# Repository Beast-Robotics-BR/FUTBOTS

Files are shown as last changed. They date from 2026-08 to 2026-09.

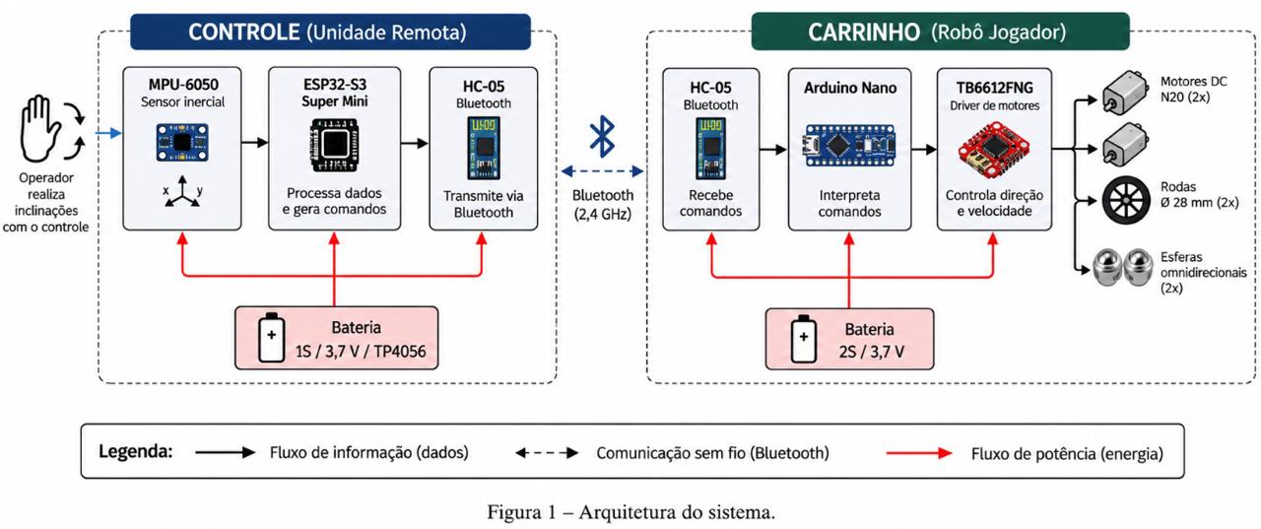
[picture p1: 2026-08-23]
Videos_de_teste/Diagrama_Visual.jpeg

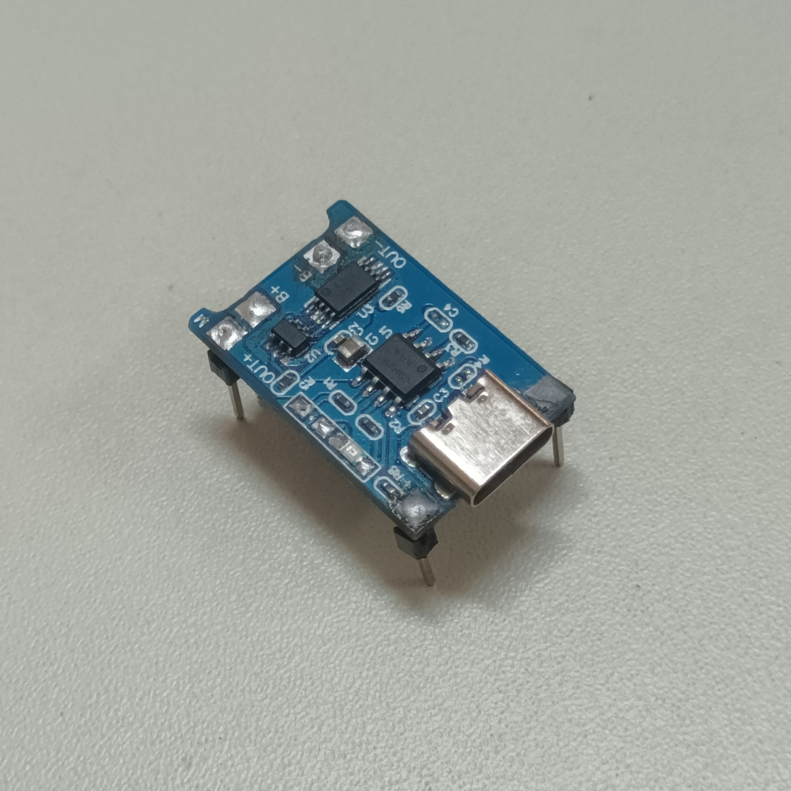
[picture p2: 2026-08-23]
Componentes/TP-4056.jpg

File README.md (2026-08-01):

# CARRINHO ROBÓTICO COM CONTROLE POR GESTOS PARA ROBÔS JOGADORES EM ARENAS DE COMPETIÇÃO: UMA APLICAÇÃO EM FUTEBOL DE ROBÔS

Este repositório reúne os materiais de **hardware** e **software** desenvolvidos para um carrinho controlado remotamente por gestos, com comunicação via **Bluetooth Low Energy (BLE)**, projetado para atuar como robô jogador em **arenas de futebol de robôs**.

---

## ⚠️ Novas Funcionalidades Em Desenvolvimento

### 🎮 Novo Controle Remoto (estilo Gamepad)
- Prezamos pela experiência de uso e, por isso, iniciamos o desenvolvimento de um controle remoto no estilo *gamepad*
- O formato mais clássico facilita a operação em diferentes situações e para diferentes públicos
- Display **OLED** integrado ao controle, capaz de fornecer informações úteis durante a operação
- Longa duração de bateria continua sendo prioridade no novo modelo

---

## Visão Geral

O projeto consiste em um **kit robótico de baixo custo e fácil operação**. Pensamos também na facilidade de reparo e, por isso, optamos por uma abordagem que se beneficia do uso de **software livre (código aberto)** e **manufatura aditiva**. Nosso kit é reparável com poucas ferramentas, além de ter sido projetado para ser resistente e de qualidade.

### Funcionalidades Principais:
- Controle remoto **gestual**, por meio de um sensor inercial (IMU), embarcado no próprio controle
- Controle alternativo via **celular**, tanto para operação normal quanto para testes e ajustes
- Comunicação sem fio via **BLE**, com vinculação por endereço MAC para conexões estáveis
- Múltiplos **níveis de intensidade de PWM**, selecionáveis durante a operação
- **Gatilhos físicos** e **botão multifunção** para ações rápidas de controle
- **Programação por blocos**, através de um web app, permitindo customizar o comportamento do carrinho
- Painel de depuração via **Web Bluetooth**, acessível pelo navegador

---

## 🛠 Hardware

### Componentes Principais
- **ESP32-S3 Super Mini** — controladora central, embarcada no controle remoto
- **Arduino Nano** — controlador embarcado no carrinho
- **Módulo IMU (MPU-6050)** — leitura de inclinação (pitch/roll) para o controle gestual
- **Display OLED SSD1306** (interface SPI, 7 pinos) — feedback visual no controle
- **Gatilhos físicos** e **botão multifunção**
- Comunicação via **Bluetooth Low Energy (BLE)**, compatível com **Web Bluetooth**

---

## 🔧 Arquitetura de Comunicação

- Comunicação **BLE** entre o controle (ESP32-S3) e o carrinho (Arduino Nano)
- Uso do **Nordic UART Service** para garantir compatibilidade com **Web Bluetooth**
- **Vinculação por MAC address**, salva em memória não volátil (NVS), evitando reconexões indesejadas com outros dispositivos
- **Modo CONFIG**: o ESP32 passa a anunciar com UUIDs proprietários de 128 bits, permitindo o envio e o salvamento de perfis de PWM na memória do dispositivo
- **Painel de depuração Web Bluetooth (HTML)**, com múltiplos modos de conexão, D-pad virtual, monitor serial e contadores de pacotes TX/RX

---

## 🎮 Sistema de Controle Gestual

- Leitura de **pitch/roll** via MPU-6050, traduzida em comandos de direção do carrinho
- **Três níveis de intensidade de PWM**, ajustáveis conforme a situação de jogo
- **Gatilhos físicos** (GPIO) para funções adicionais de controle
- **Botão multifunção**:
  - 1 clique → recalibração do sensor
  - 2 cliques → bloqueia/desbloqueia o controle
  - Pressão longa (5s) → entra no **modo CONFIG**

---

## ⚙️ Notas Técnicas

- Durante o desenvolvimento, identificamos que módulos baratos vendidos como "HC-05" eram, na verdade, clones com chip Jieli, operando com serviço/característica BLE próprios — o que exigiu ajustes no mapeamento de UUIDs
- A arquitetura de comunicação BLE passou por múltiplas revisões (filtros de escaneamento, arquitetura de callbacks) até garantir estabilidade de conexão

---

## 🎯 Aplicações

- Robô jogador em **arenas de futebol de robôs** e competições similares
- Ensino de **robótica e automação** com foco em controle gestual
- Base para **prototipagem** de sistemas de controle remoto sem fio de baixo custo

---

## Muito obrigado pela atenção !!!

---

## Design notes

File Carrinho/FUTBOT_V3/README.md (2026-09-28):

# RoverLab V3 Modular

Firmware para Arduino Nano + TB6612FNG + HM-10 com controle manual, perfil PWM, EEPROM e programação por blocos.

## Arquivos

- `FUTBOT_V3.ino`: aplicação principal, protocolo, motores, EEPROM e executor de blocos.
- `Config.h`: pinagem, parâmetros e seleção de polaridade.
- `Leds.h`: estados e padrões dos LEDs.

Abra o arquivo `FUTBOT_V3.ino` pelo Arduino IDE mantendo os três arquivos na mesma pasta.

## Escolha do tipo de LED

Edite somente esta linha em `Config.h`:

```cpp
const bool LED_ACTIVE_HIGH = true;
```

Use:

```cpp
true  // catodo comum: HIGH acende
false // anodo comum: LOW acende
```

Se o seu módulo LED tiver transistores ou uma placa intermediária que inverta o sinal, use o valor que corresponde ao nível lógico que efetivamente acende o LED.

## Estados dos LEDs

- Azul fixo: BLE conectado.
- Azul piscando: BLE desconectado.
- Vermelho pulsando: janela de configuração desbloqueada.
- Vermelho fixo: reservado para falha crítica.
- Verdes fixos em quantidade 1, 2 ou 3: nível de movimento selecionado.
- Verde alternado: upload de programa em andamento.
- Verde correndo: programa por blocos em execução.

Os pinos permanecem:

| LED | Pino |
|---|---:|
| Verde 1 | D6 |
| Verde 2 | D9 |
| Verde 3 | D10 |
| Vermelho | D4 |
| Azul | D2 |

## Configuração indispensável

O perfil de velocidade continua disponível no protocolo V3:

```text
@C,UNLOCK*CRC8;
@C,PROFILE,45,85,135*CRC8;
@C,GET*CRC8;
```

A alteração só é aceita dentro da janela de 5 segundos após `UNLOCK`. O perfil é validado e gravado em dois slots alternados da EEPROM.

A programação por blocos continua usando:

```text
@P,BEGIN,TAMANHO,CRC16*CRC8;
@P,DATA,OFFSET,HEX*CRC8;
@P,COMMIT*CRC8;
@P,START*CRC8;
@P,STOP*CRC8;
```

## Teste inicial

1. Selecione `LED_ACTIVE_HIGH` conforme o carrinho.
2. Grave o firmware com as rodas suspensas.
3. Abra o terminal em 38400 baud.
4. Confira o azul: ele deve piscar desconectado e ficar fixo conectado.
5. Envie `@C,UNLOCK*3B;`. O vermelho deve pulsar por 5 segundos.
6. Envie o perfil de teste e observe os LEDs verdes.
7. Teste o programa por blocos e mantenha `@P,STOP*0A;` acessível.

## Watchdog e execução de blocos

O watchdog de 300 ms protege somente o modo manual. Durante `P,START`, o executor mantém o programa ativo até a duração de cada passo terminar; assim, `01 01 32` permanece avançando por 5 segundos. A troca entre passos ocorre na expiração do passo, sem pausa artificial. `P,STOP` e o frame enquadrado `STOP` continuam interrompendo imediatamente o programa e os motores.

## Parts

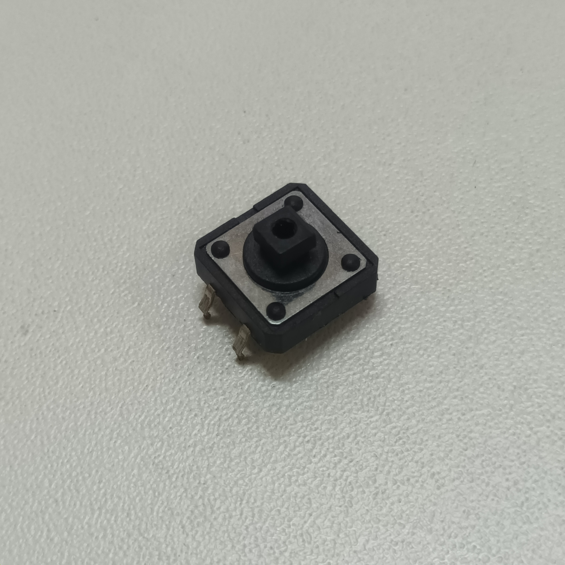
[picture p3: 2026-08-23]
Componentes/BOTÃO 12MM.jpg

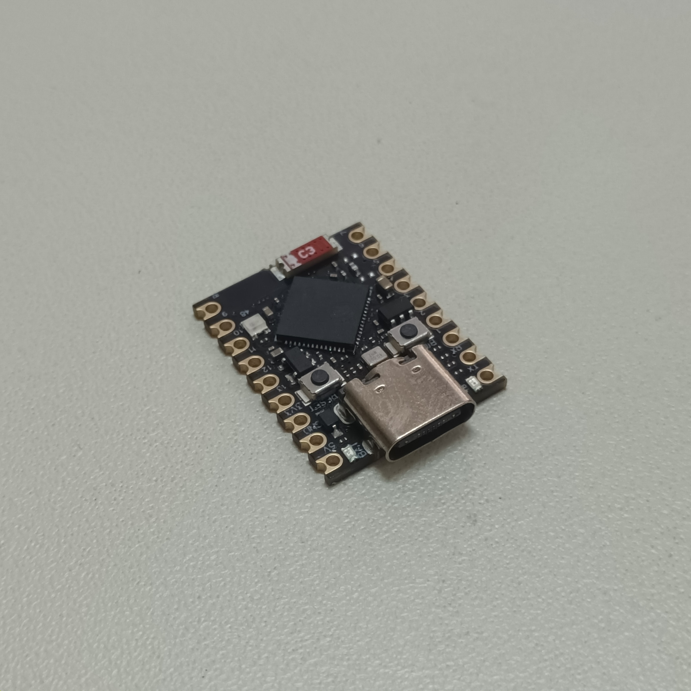
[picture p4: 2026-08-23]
Componentes/ESP32-S3.jpg

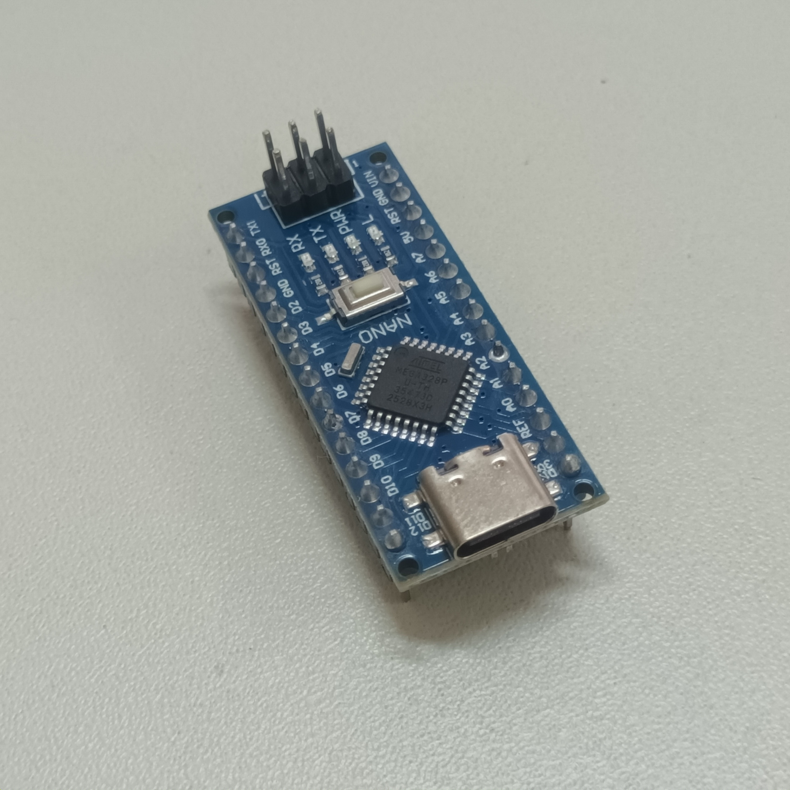
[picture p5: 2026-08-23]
Componentes/ARDUINO-NANO.jpg

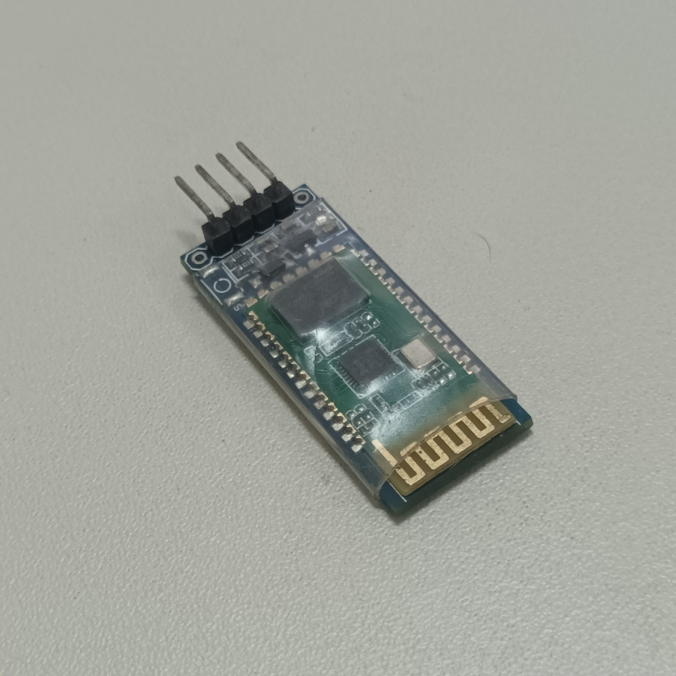
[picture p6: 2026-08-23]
Componentes/HC-05.jpg

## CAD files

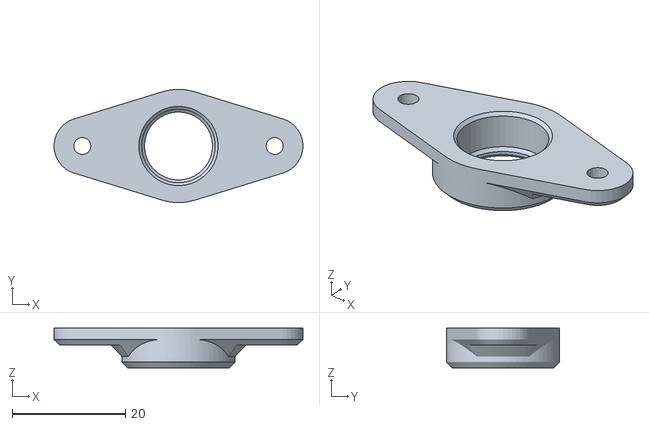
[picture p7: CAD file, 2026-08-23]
Carrinho/Modelos-3D/TRAVA_ESFERA.stl
44.0 x 20.0 x 7.00

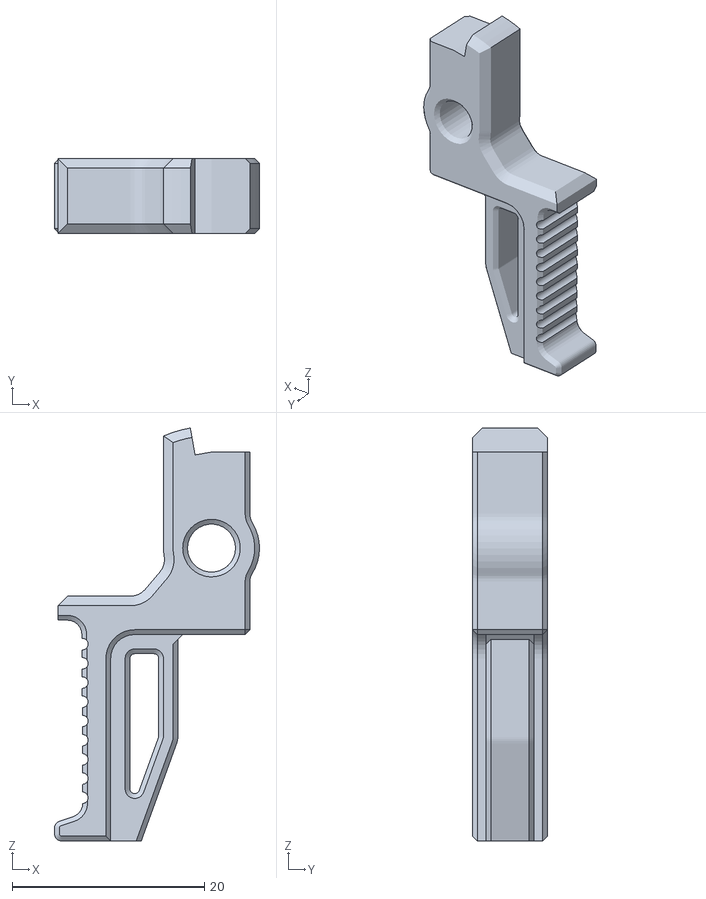
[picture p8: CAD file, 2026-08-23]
Controle_Gestual/Modelos-3D/Gatilho.stl
21.4 x 7.80 x 43.0

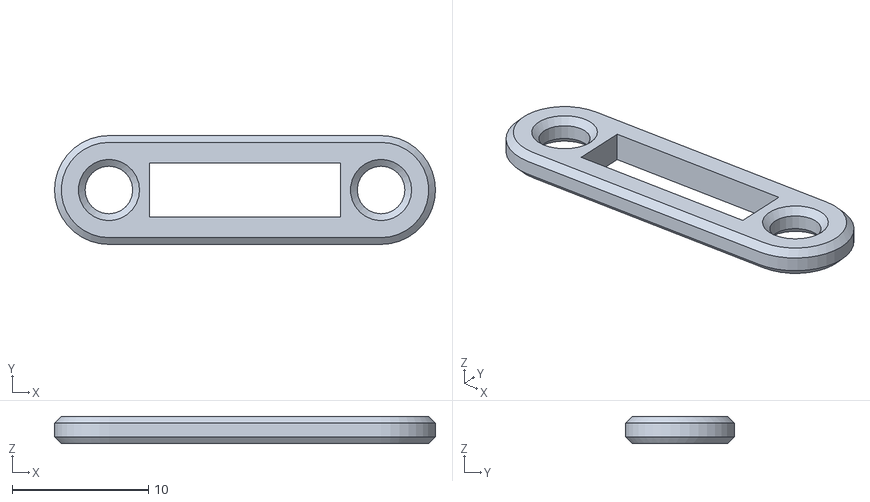
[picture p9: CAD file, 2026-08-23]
Carrinho/Modelos-3D/TRAVA_INTERRUPTOR.stl
28.0 x 8.00 x 2.00

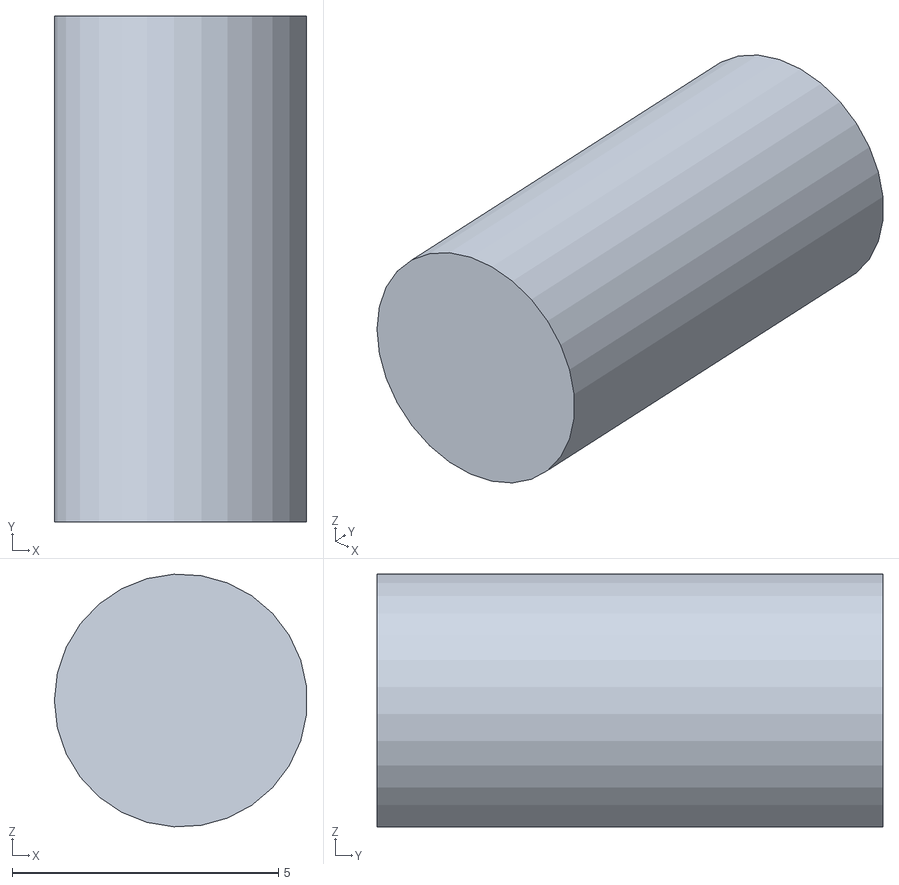
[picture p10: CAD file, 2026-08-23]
Controle_Gestual/Modelos-3D/Eixo_gatilho.stl
4.74 x 9.50 x 4.74

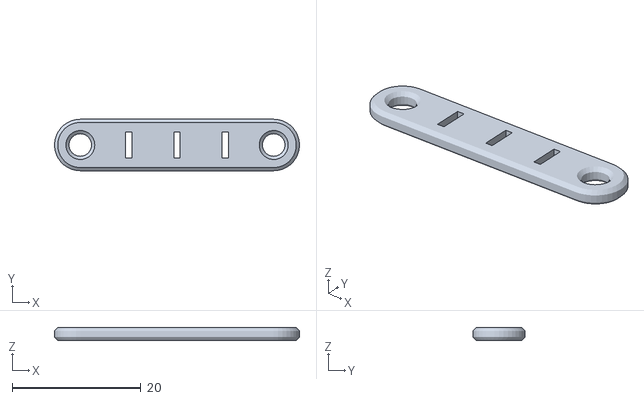
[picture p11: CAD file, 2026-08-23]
Carrinho/Modelos-3D/TRAVA_LEDS.stl
38.0 x 8.00 x 2.00

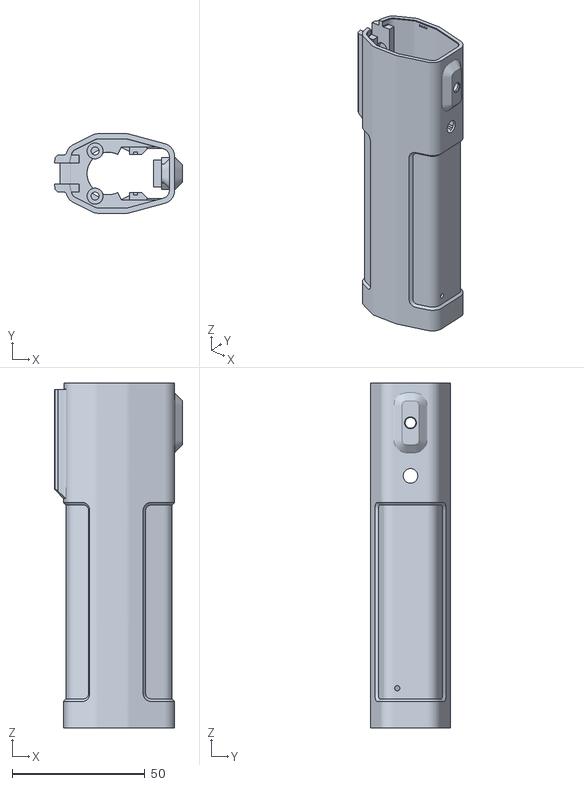
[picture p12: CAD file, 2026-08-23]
Controle_Gestual/Modelos-3D/Corpo_principal.stl
48.3 x 30.0 x 130.0

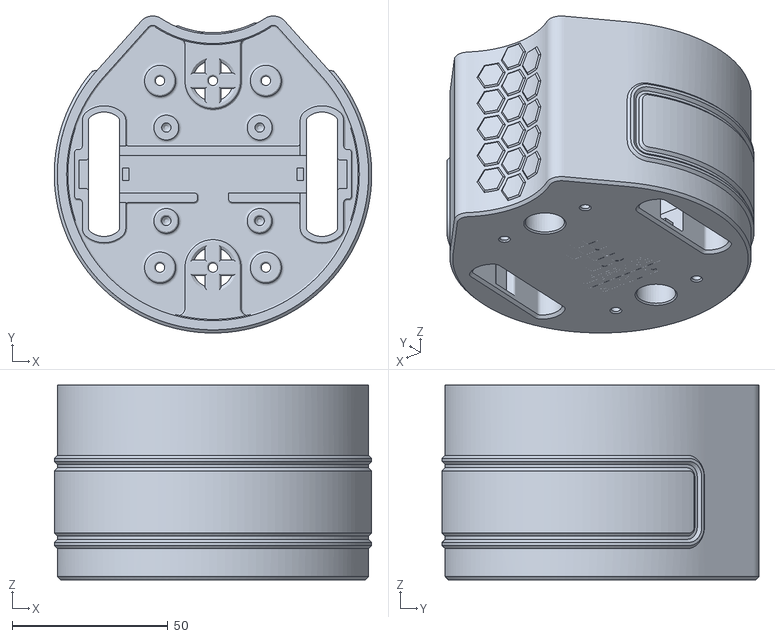
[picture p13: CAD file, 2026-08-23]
Carrinho/Modelos-3D/CASE_EXT.stl
102.0 x 101.8 x 62.5

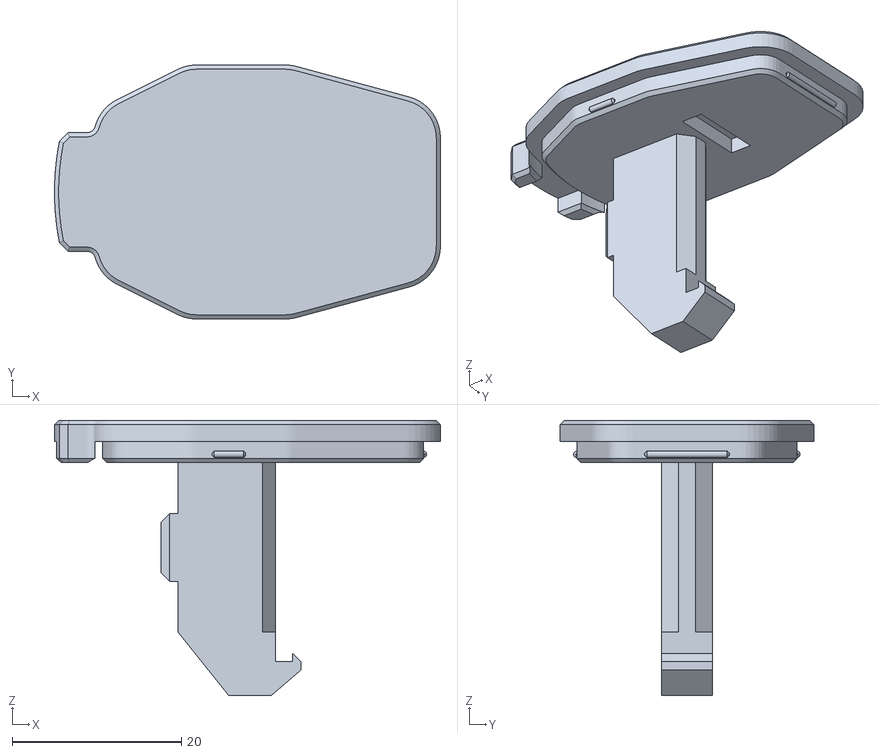
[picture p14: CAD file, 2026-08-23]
Controle_Gestual/Modelos-3D/Tampa_superior.stl
45.6 x 30.0 x 32.5

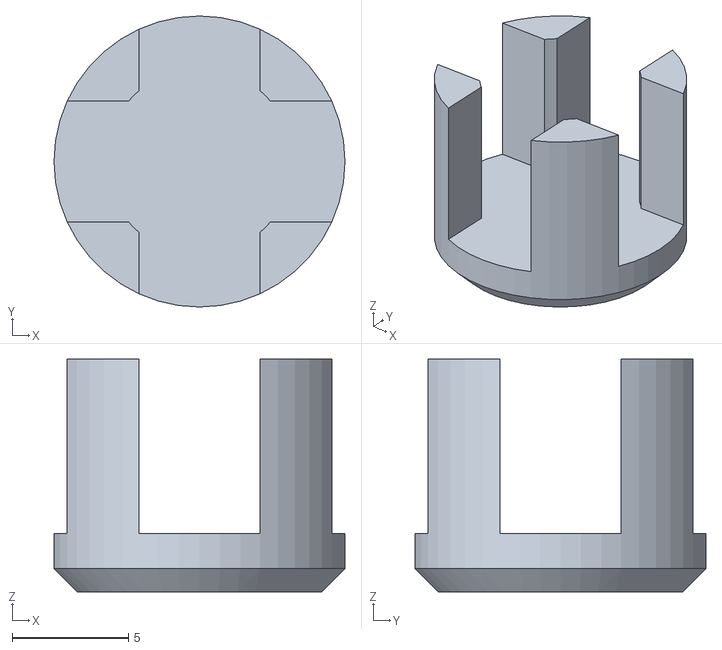
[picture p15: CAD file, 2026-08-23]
Carrinho/Modelos-3D/ESF_AJUSTE.stl
12.5 x 12.5 x 10.0

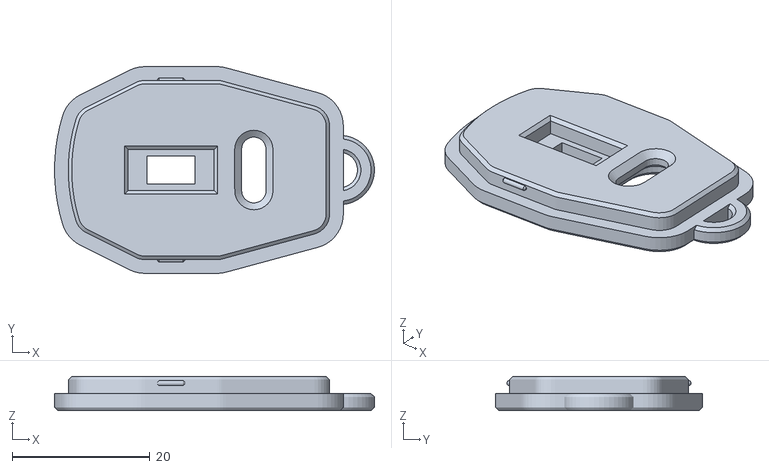
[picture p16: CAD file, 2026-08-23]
Controle_Gestual/Modelos-3D/Tampa_inferior.stl
46.4 x 30.0 x 5.00

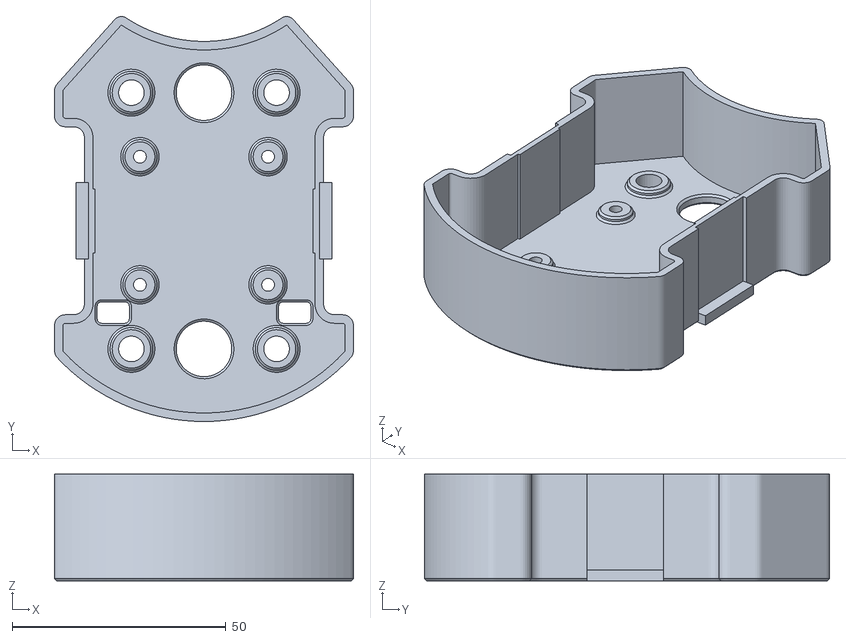
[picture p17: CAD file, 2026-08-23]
Carrinho/Modelos-3D/CASE_INT.stl
70.1 x 94.8 x 25.0

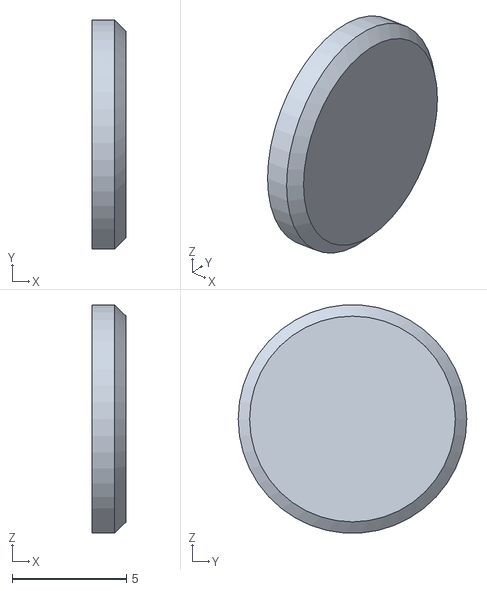
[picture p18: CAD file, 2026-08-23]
Controle_Gestual/Modelos-3D/Botão_externo.stl
1.50 x 10.0 x 9.97

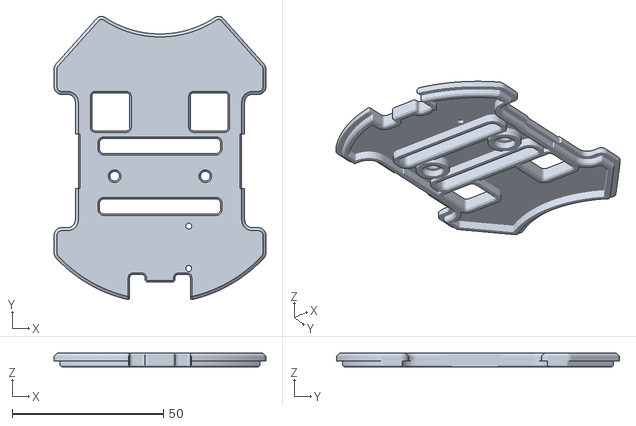
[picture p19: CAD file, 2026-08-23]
Carrinho/Modelos-3D/TAMPA_CASE_INT.stl
70.1 x 93.6 x 4.50

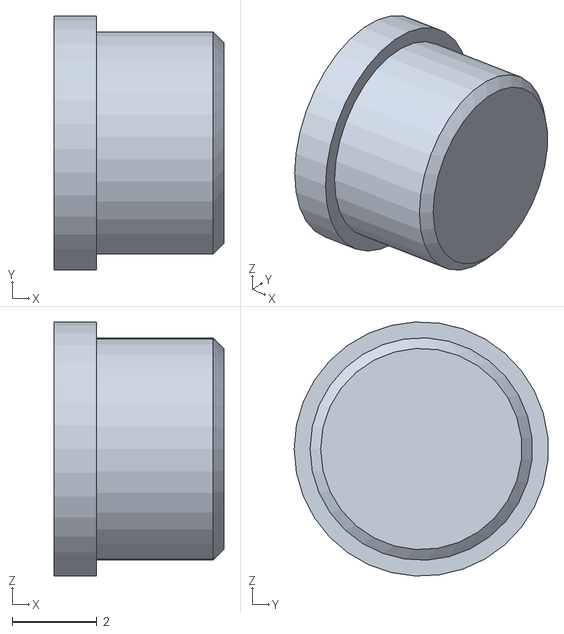
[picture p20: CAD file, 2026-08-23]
Controle_Gestual/Modelos-3D/Botão_interno.stl
4.00 x 5.99 x 5.99

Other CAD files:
Carrinho/Modelos-3D/TAMPA_SUP.stl
Carrinho/Modelos-3D/TAMPA_CAIXA_RODA.stl

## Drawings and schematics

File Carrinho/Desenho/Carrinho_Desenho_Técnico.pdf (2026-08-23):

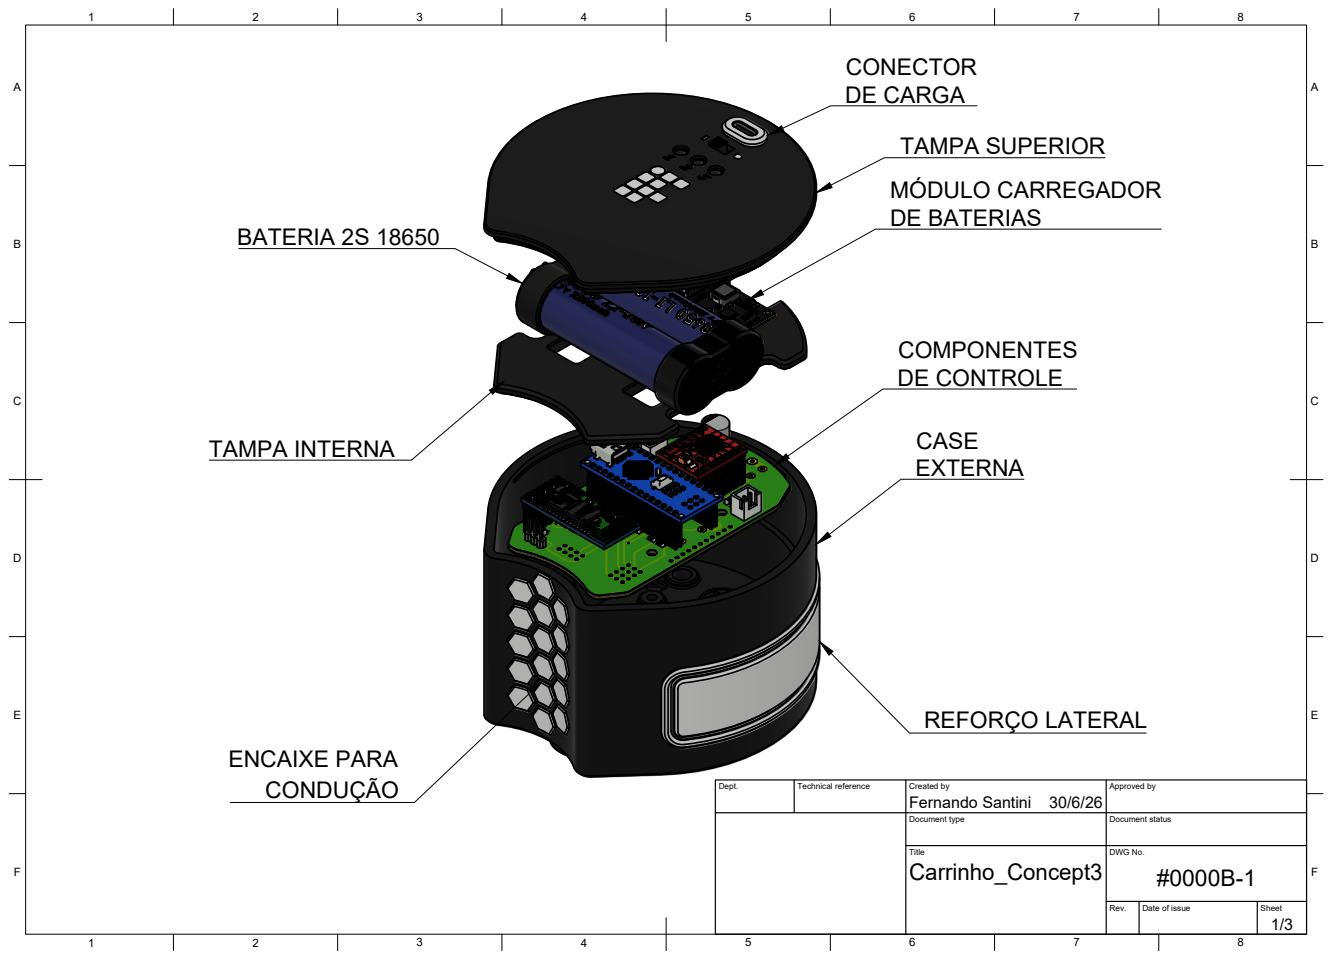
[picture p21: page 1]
Dept.; Technical reference; Created by; Approved by; Document type; Document status; Title; DWG No.; Rev.; Date of issue; Sheet; Fernando Santini; TAMPA SUPERIOR; DE CARGA; MÓDULO CARREGADOR DE BATERIAS; TAMPA INTERNA; BATERIA 2S 18650; DE CONTROLE; REFORÇO LATERAL; ENCAIXE PARA

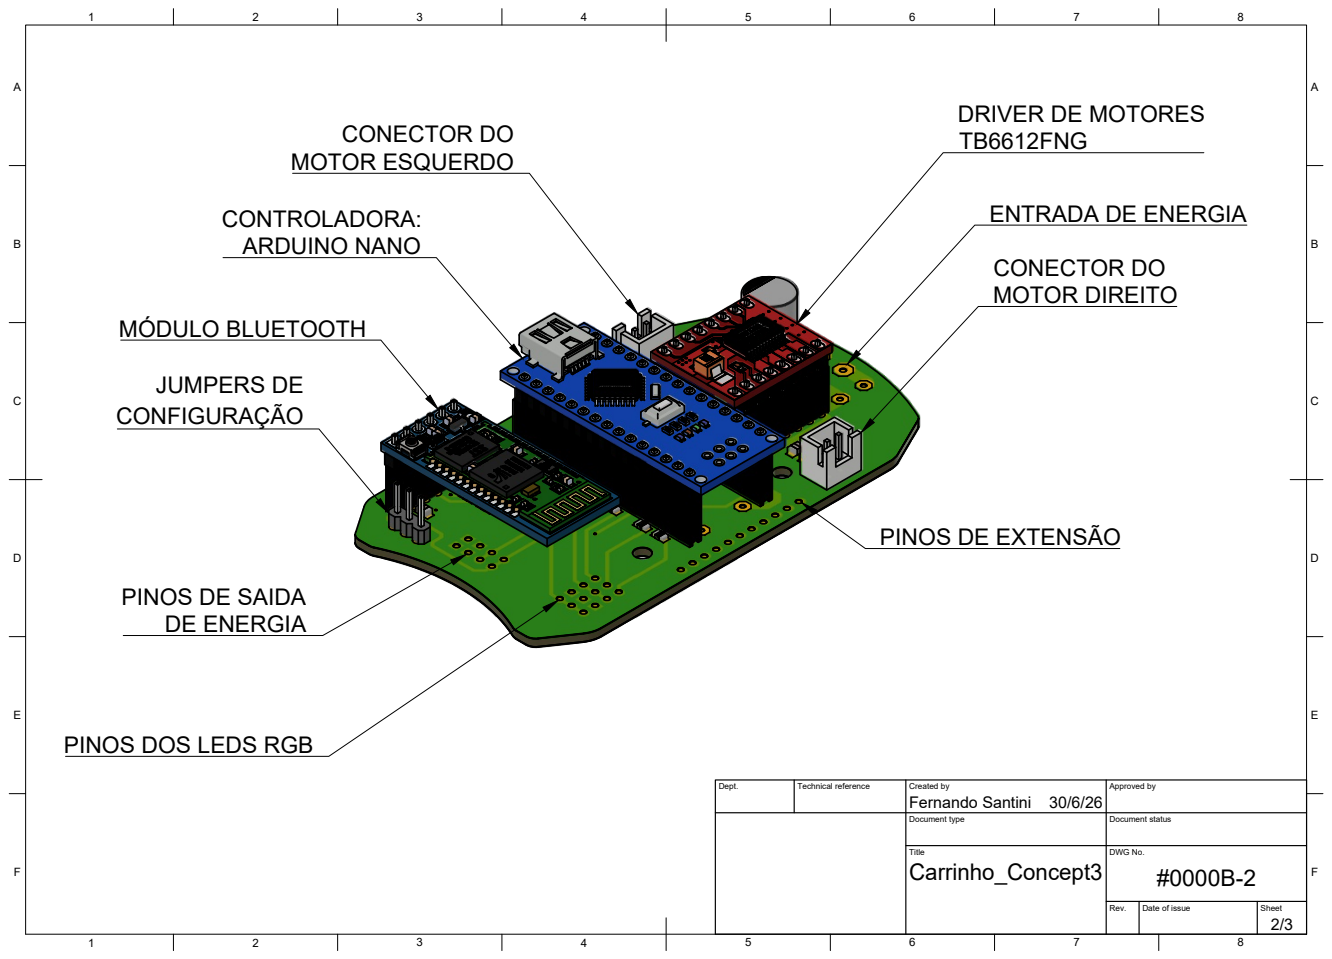
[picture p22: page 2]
Title; DWG No.; CONECTOR DO MOTOR ESQUERDO; CONECTOR DO MOTOR DIREITO; ARDUINO NANO; MÓDULO BLUETOOTH; JUMPERS DE

DRIVER DE MOTORES
TB6612FNG

ENTRADA DE ENERGIA

PINOS DE EXTENSÃO

PINOS DE SAIDA
DE ENERGIA

PINOS DOS LEDS RGB

Dept. | Technical reference | Created by Fernando Santini 30/6/26 | Approved by

Document type | Document status

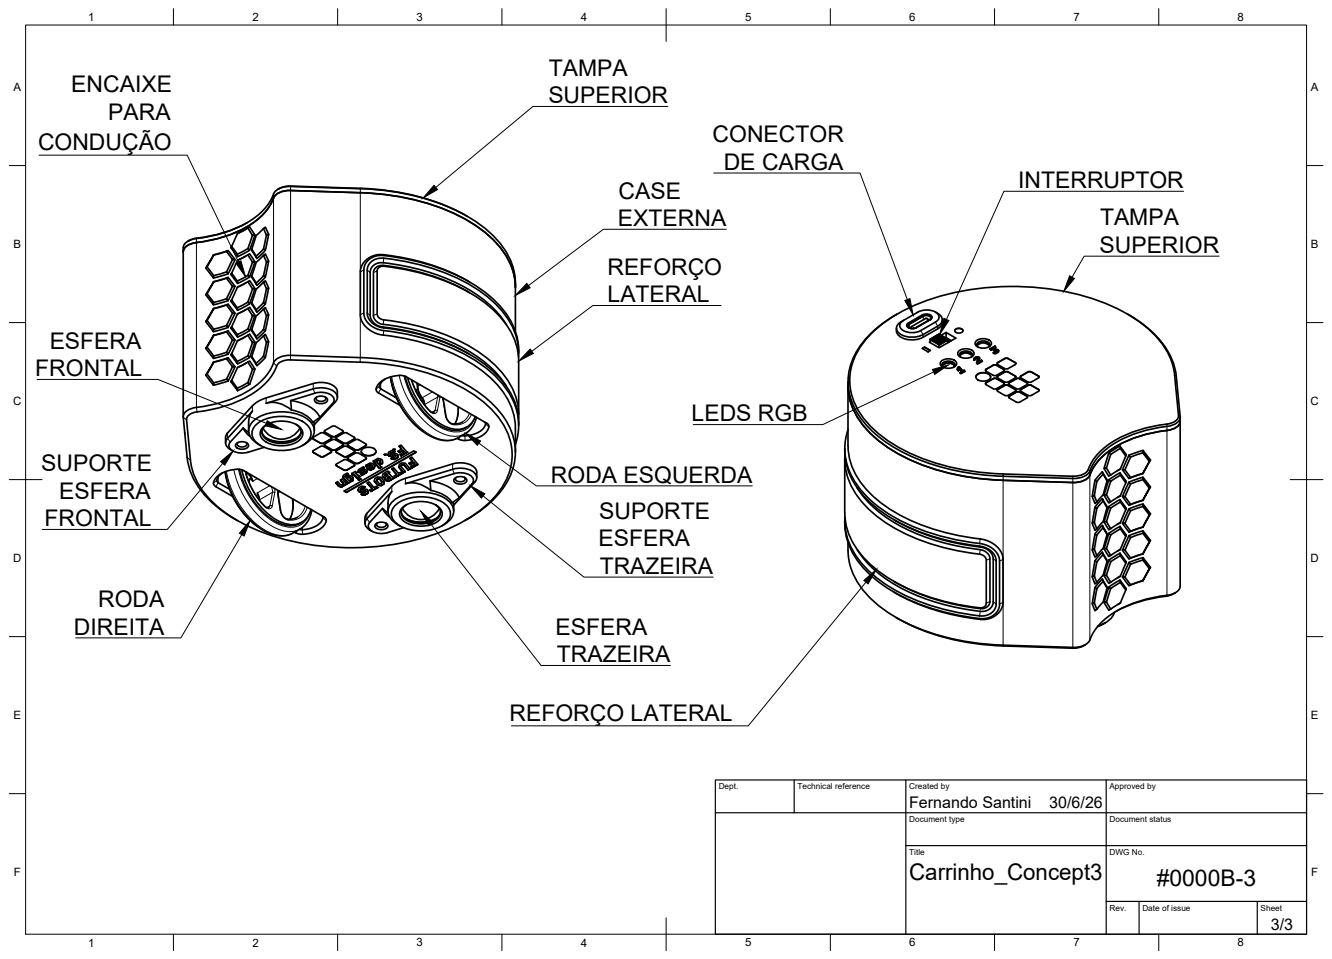
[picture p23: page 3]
Title; DWG No.; RODA ESQUERDA; DE CARGA; LEDS RGB; REFORÇO LATERAL

Dept. | Technical reference | Created by Fernando Santini 30/6/26 | Approved by

Document type | Document status

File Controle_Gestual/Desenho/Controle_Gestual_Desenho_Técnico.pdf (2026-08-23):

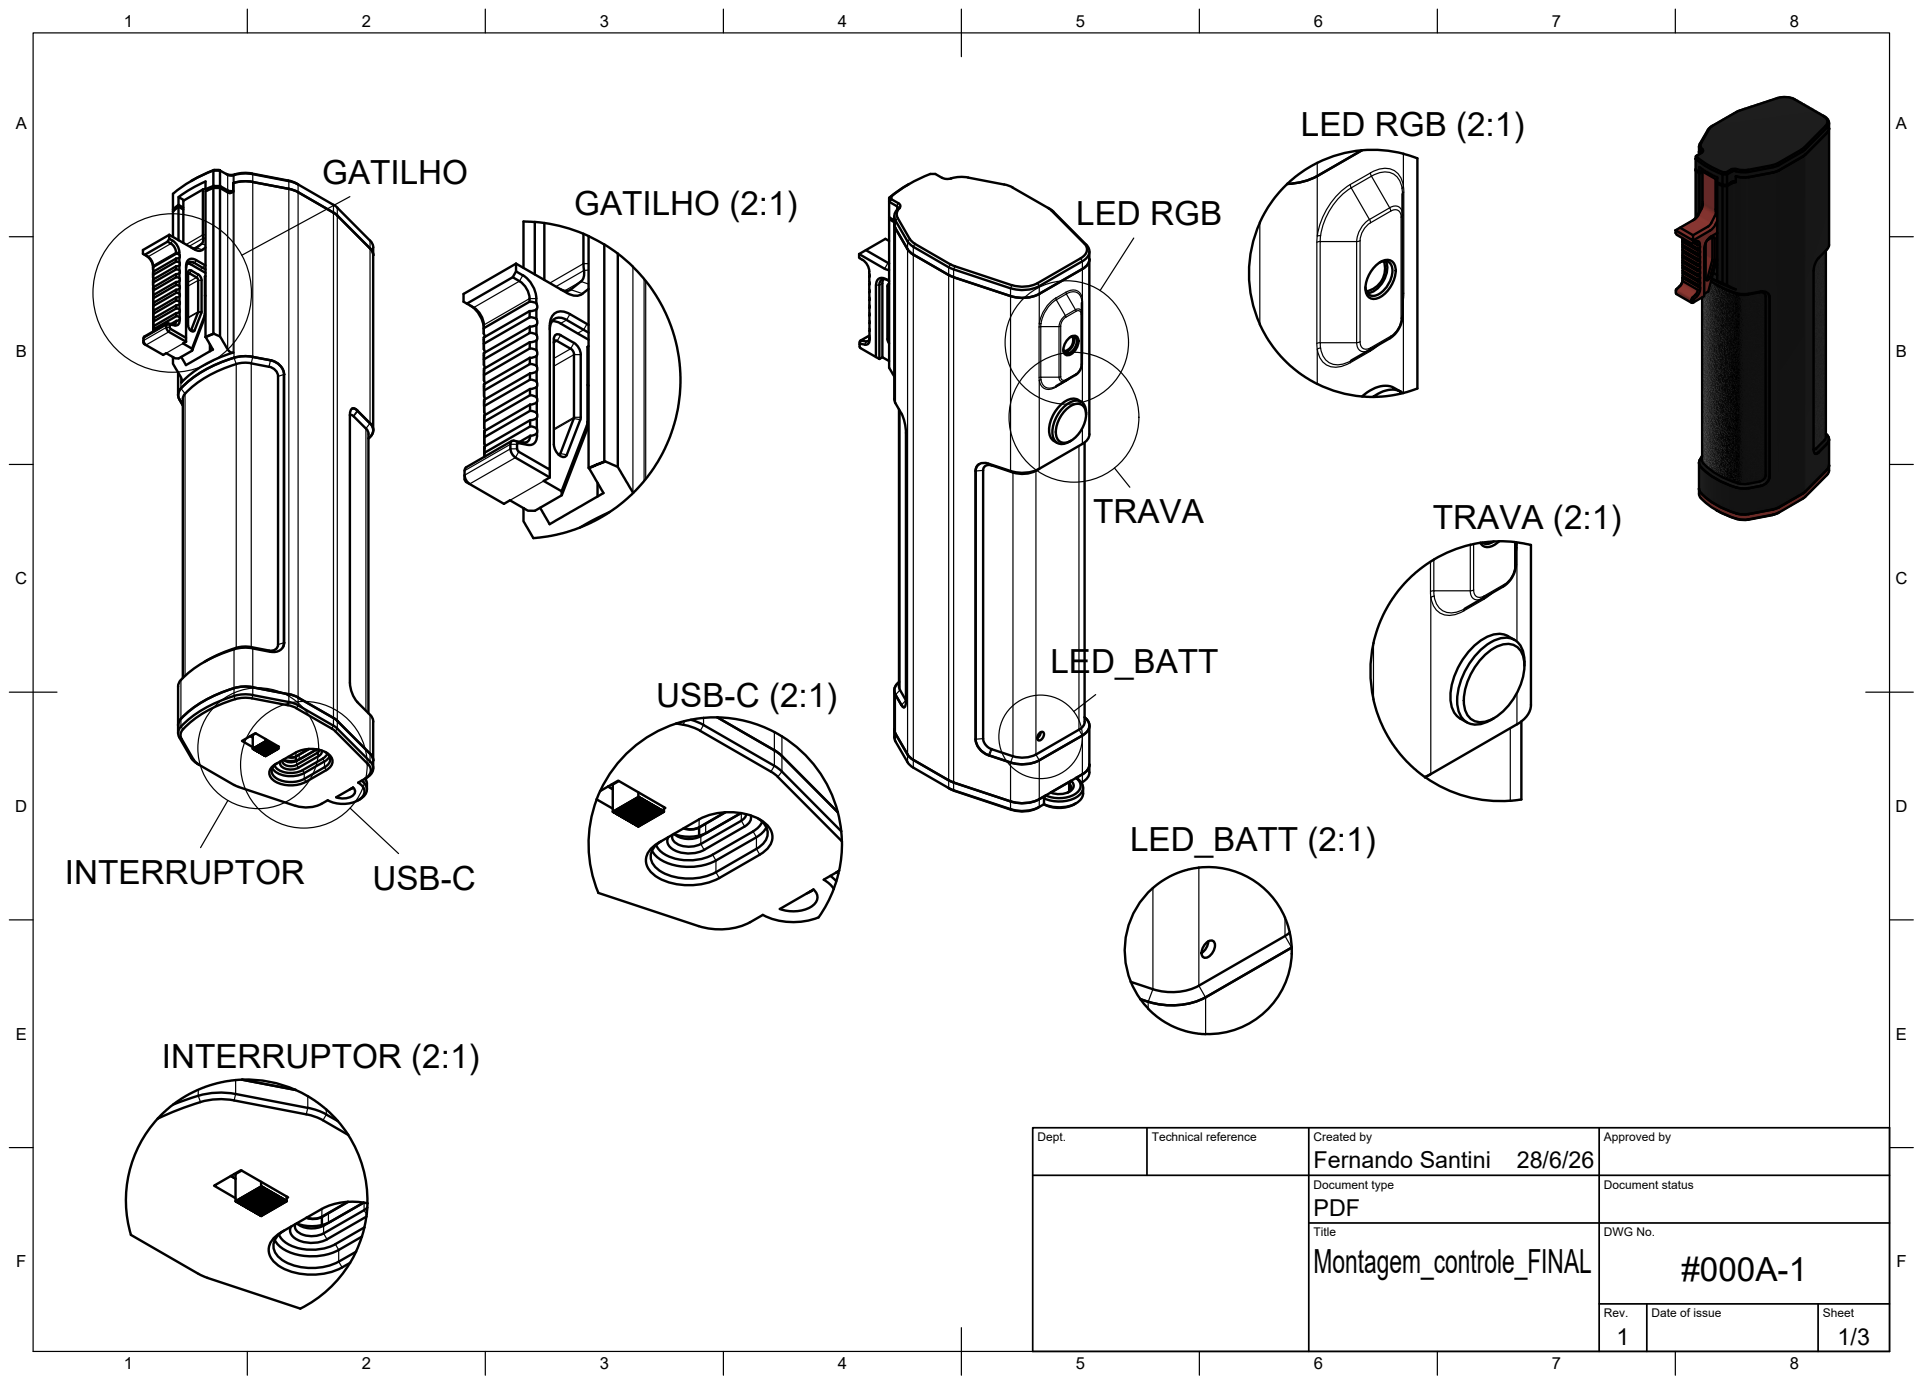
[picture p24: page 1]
Title; DWG No.; Rev.; Date of issue; Sheet; GATILHO (2:1); INTERRUPTOR (2:1); USB-C (2:1); LED RGB; LED RGB (2:1); TRAVA; TRAVA (2:1); LED_BATT (2:1)

Dept. | Technical reference | Created by Fernando Santini 28/6/26 | Approved by

Document type PDF | Document status

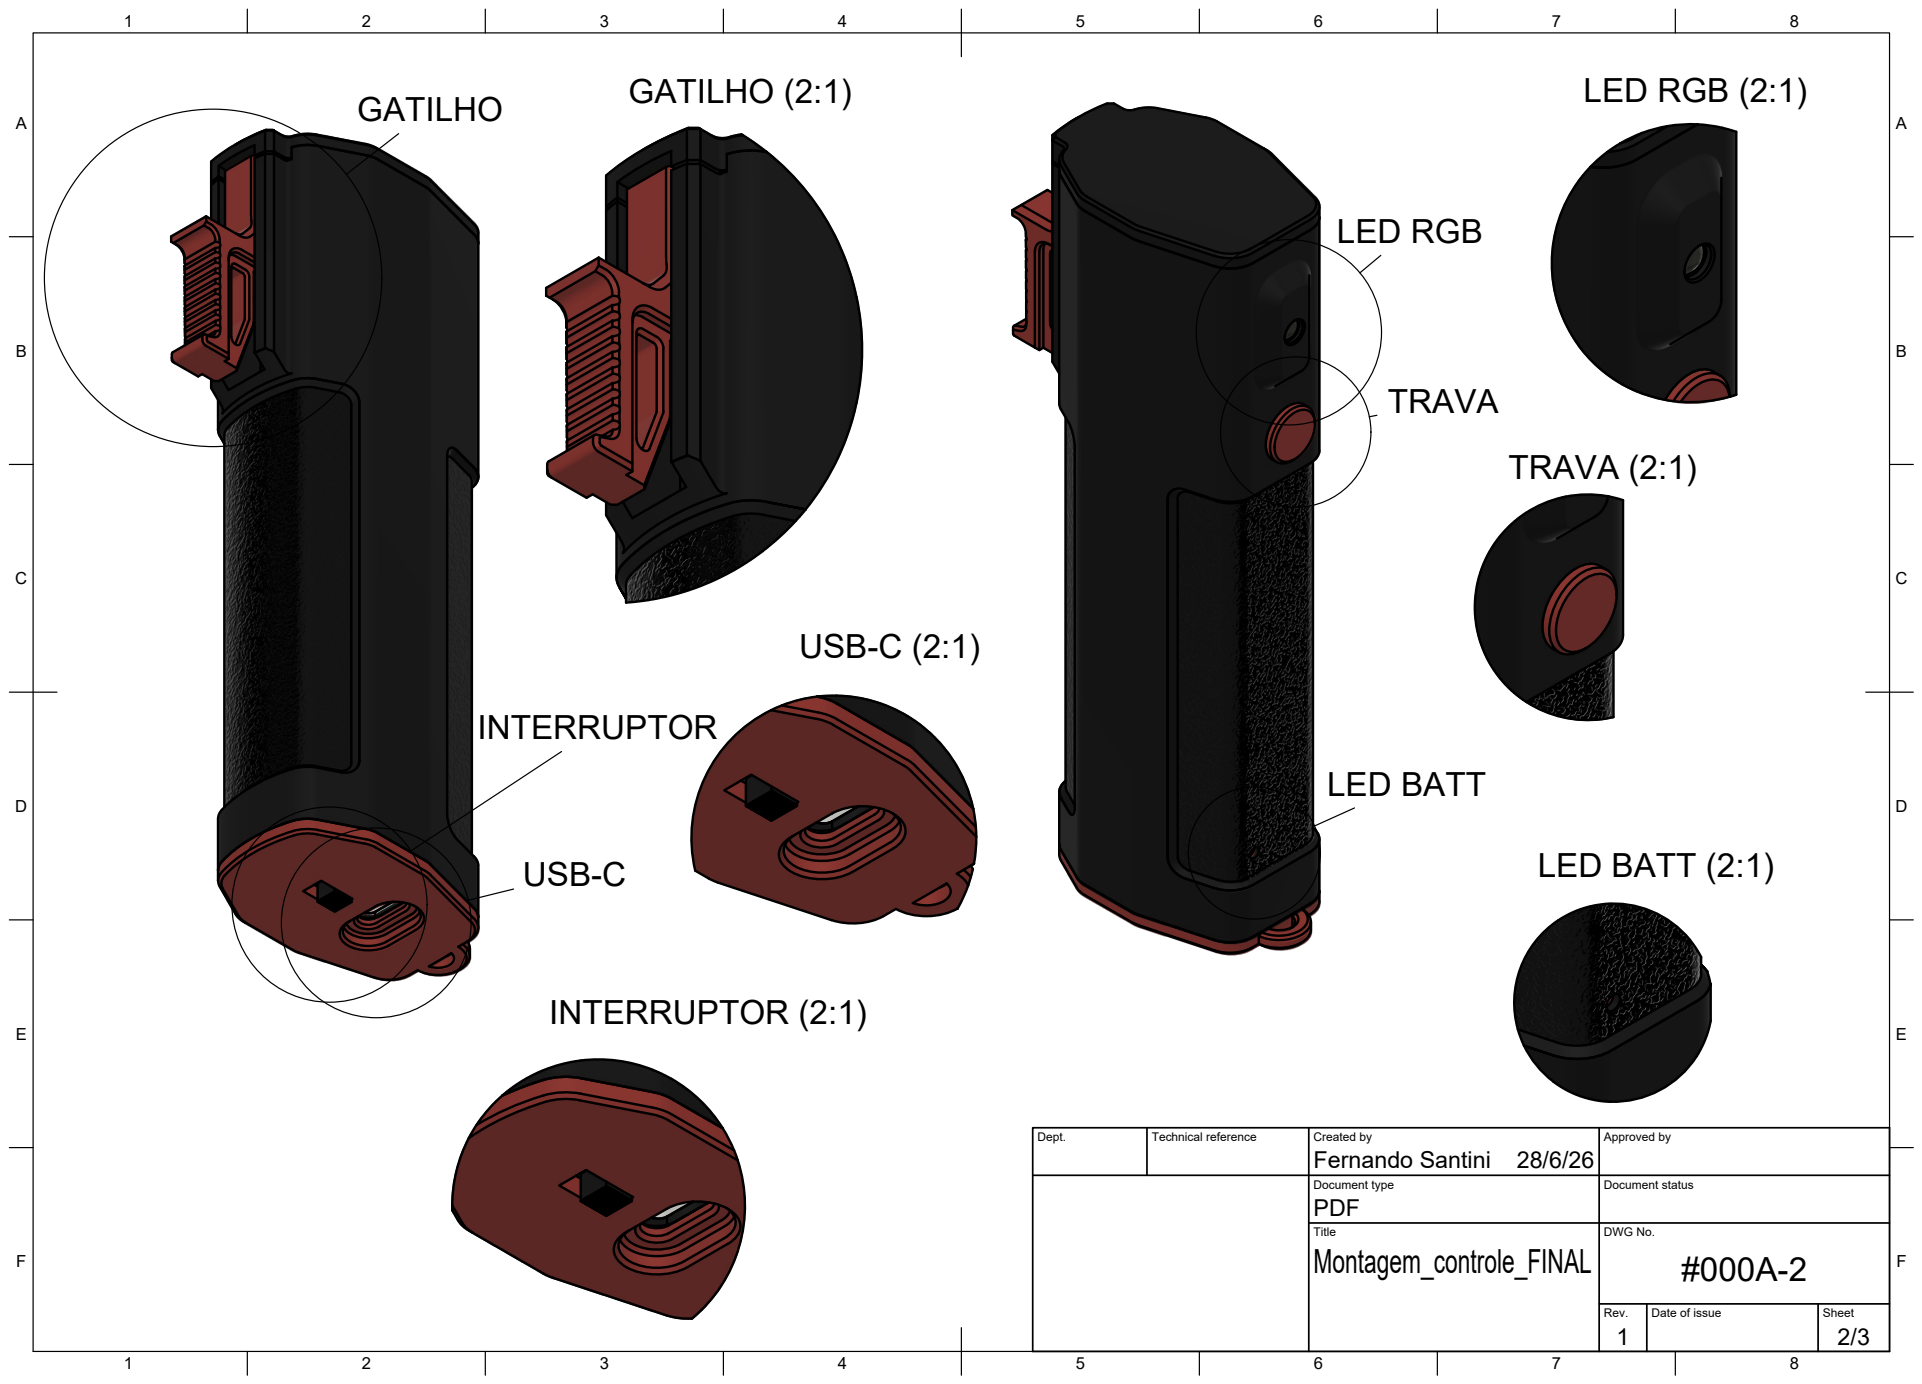
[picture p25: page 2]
Title; DWG No.; GATILHO; GATILHO (2:1); USB-C (2:1); INTERRUPTOR (2:1); LED RGB; LED RGB (2:1); TRAVA (2:1); LED BATT; LED BATT (2:1)

Dept. | Technical reference | Created by Fernando Santini 28/6/26 | Approved by

Document type PDF | Document status

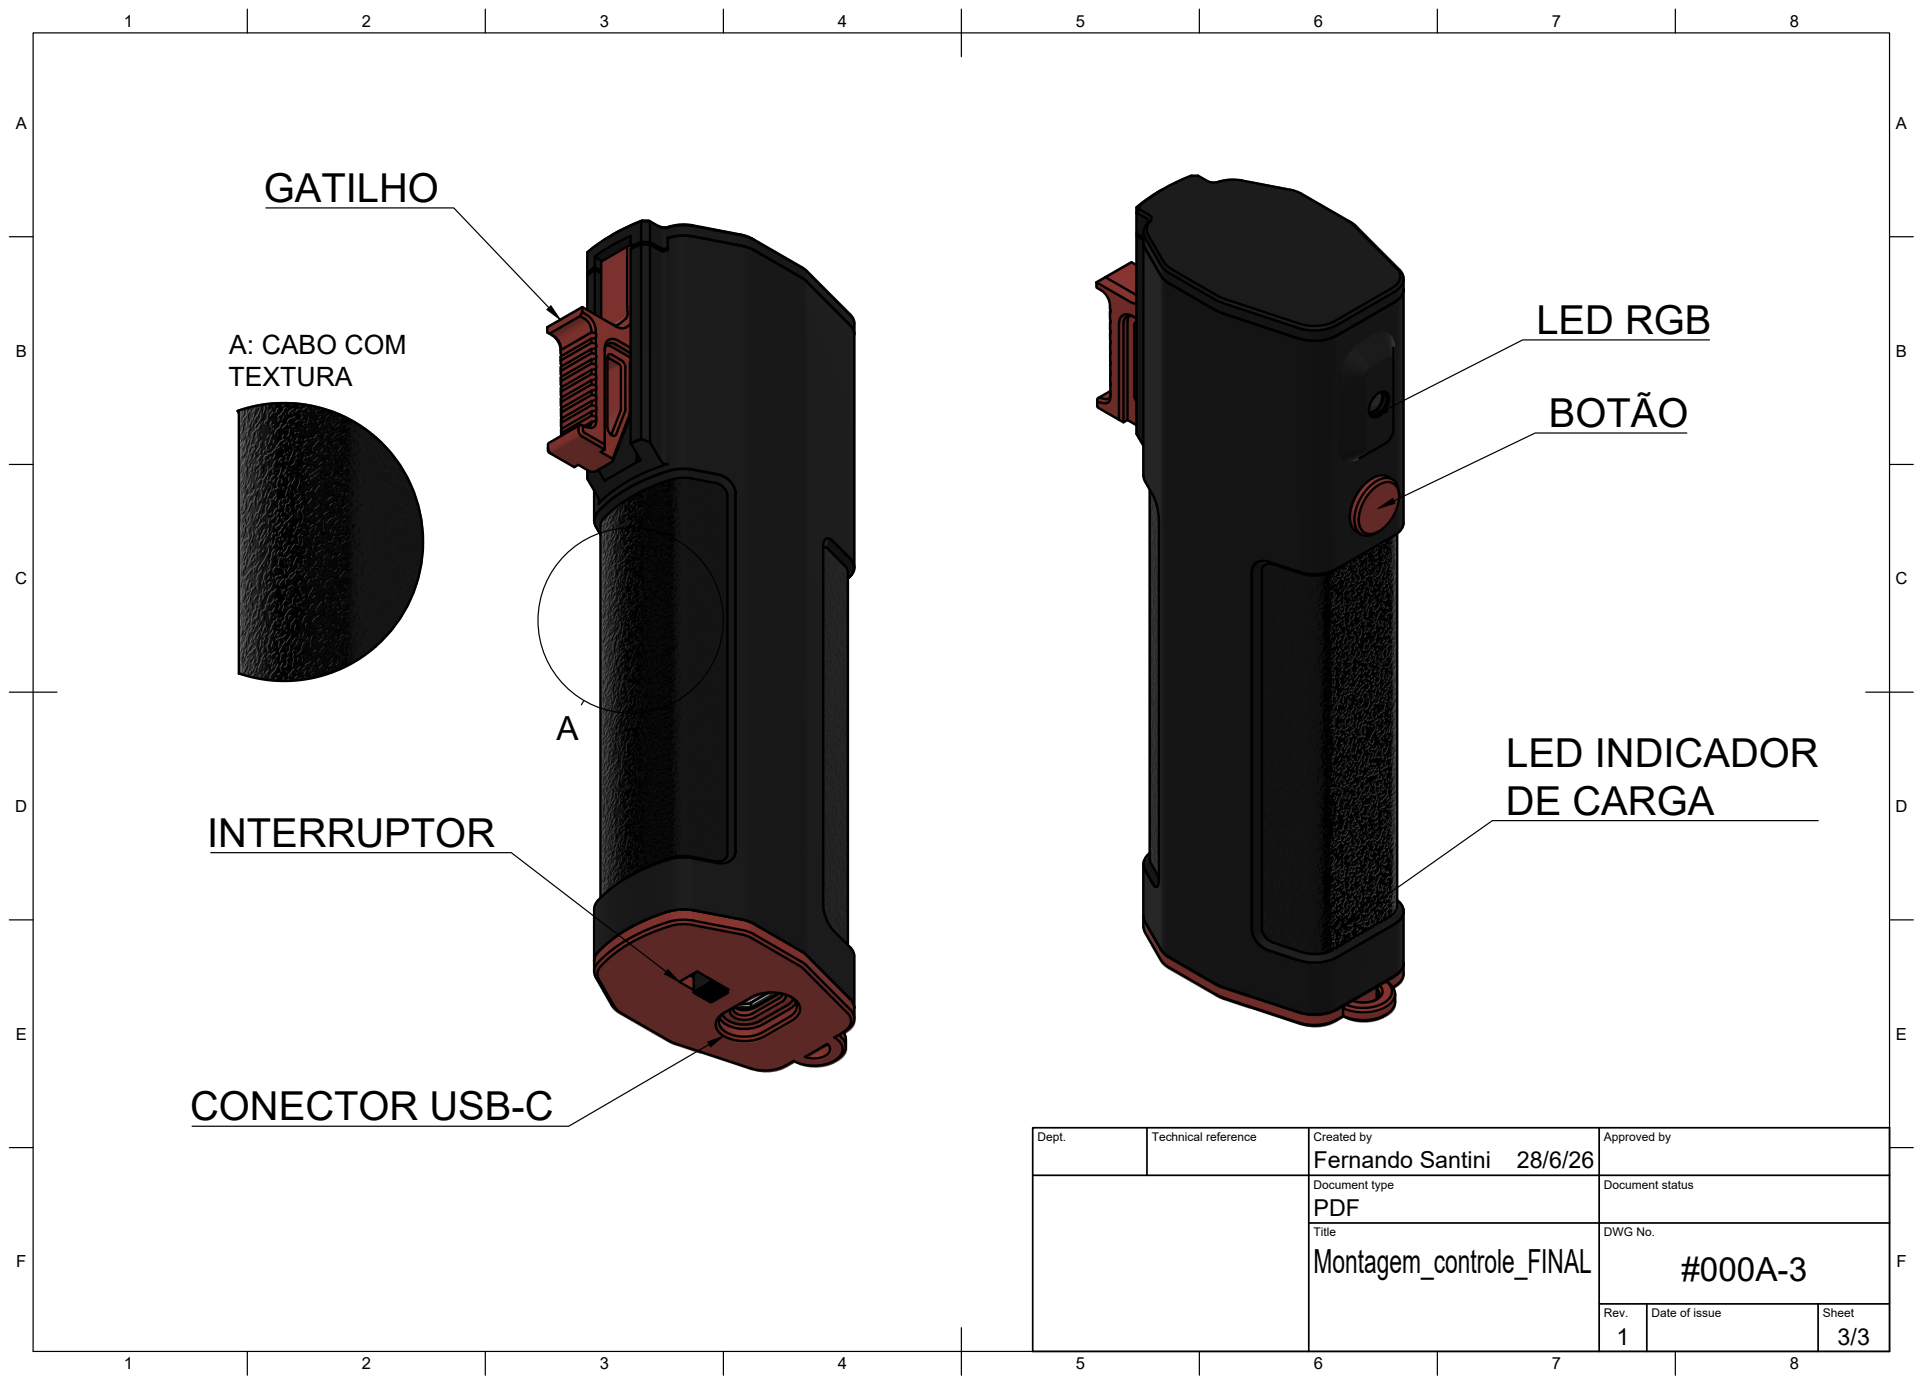
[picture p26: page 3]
Title; DWG No.; LED INDICADOR DE CARGA; LED RGB; A: CABO COM; CONECTOR USB-C

Dept. | Technical reference | Created by Fernando Santini 28/6/26 | Approved by

Document type PDF | Document status

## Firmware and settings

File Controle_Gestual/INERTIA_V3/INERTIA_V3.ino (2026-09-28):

/*
 * Controle BLE V3 — ESP32-S3 + MPU6050 + gatilho
 *
 * Sem Wi-Fi e sem WebServer. O controle pode conectar ao carrinho enquanto
 * permanece travado; nenhum comando de movimento é transmitido até UNLOCK.
 * Ajustes locais são feitos pelo monitor serial USB.
 *
 * Pinos:
 * BTN_FRONT=2, BTN_BACK=3, LED_R=4, LED_G=5, LED_B=6,
 * SDA=8, SCL=9, BTN_LOCK=10, BUZZER=48.
 *
 * Botão LOCK:
 * - clique simples: recalibra os ângulos em posição neutra;
 * - duplo clique: alterna LOCK/NORMAL;
 * - segurar 5 s: entra ou sai do CONFIG BLE;
 * - segurar 10 s: limpa o vínculo e inicia novo bind.
 *
 * Console serial 115200:
 * HELP | STATUS | LOCK | UNLOCK | CAL | REBIND | ANGLES?
 * ANGLES=pitchHigh,rollLow,rollMid,rollHigh
 * PWM? | PWM=min,med,max
 *
 * BLE: serviço FFE0, característica FFE1. O padrão usa frames V3:
 * @D,V=2,R=0,S=1*CRC8;
 */

#include <Arduino.h>
#include <Wire.h>
#include <Preferences.h>
#include <BLEDevice.h>
#include <BLEUtils.h>
#include <BLEScan.h>
#include <BLEAdvertisedDevice.h>
#include <BLEClient.h>
#include <BLEServer.h>
#include <BLE2902.h>
#include <math.h>

// ---------------- Pinagem ----------------
const uint8_t BTN_FRONT = 2, BTN_BACK = 3, BTN_LOCK = 10;
const uint8_t LED_R = 4, LED_G = 5, LED_B = 6, BUZZER = 48;
const uint8_t SDA_PIN = 8, SCL_PIN = 9;

// Inversão dos sentidos lógicos da IMU. Altere para true se o movimento
// correspondente estiver invertido no carrinho. A calibração continua válida.
const bool INVERT_PITCH = false;
const bool INVERT_ROLL = false;

// Brilho máximo dos LEDs em PWM: 0 = apagado, 255 = brilho total.
// Valores entre 45 e 100 costumam ser confortáveis em LEDs fortes.
const uint8_t LED_MAX_BRIGHTNESS = 50;

// ---------------- BLE ----------------
static BLEUUID SERVICE_UUID((uint16_t)0xFFE0);
static BLEUUID DATA_UUID((uint16_t)0xFFE1);
static BLEUUID CONFIG_SERVICE_UUID("7b7e0001-6f4a-4c32-9c51-5a7f3a000001");
static BLEUUID CONFIG_CHAR_UUID("7b7e0001-6f4a-4c32-9c51-5a7f3a000002");
const char *TARGET_PREFIX = "CARRINHO";
const bool USE_V3_FRAMES = true;
const uint32_t BLE_RETRY_MS = 2500;
const uint32_t HEARTBEAT_MS = 80;

// ---------------- MPU6050 ----------------
const uint8_t MPU_ADDR = 0x68;
const uint8_t WHO_AM_I = 0x75, PWR_MGMT_1 = 0x6B, ACCEL_CONFIG = 0x1C;
const uint8_t ACCEL_XOUT_H = 0x3B;

Preferences prefs;
BLEClient *client = nullptr;
BLERemoteCharacteristic *dataChar = nullptr;
BLEAdvertisedDevice *candidate = nullptr;
BLEServer *configServer = nullptr;
BLECharacteristic *configChar = nullptr;
bool configBleActive = false;

volatile bool connectRequested = false;
volatile bool rescanRequested = false;
bool scanCallbackInstalled = false;
bool bleConnected = false;
String boundMac;
String deviceName;
uint32_t retryAt = 0;
uint32_t lastHeartbeat = 0;
uint8_t sequenceNo = 0;

// ---------------- Estado ----------------
enum ControlMode : uint8_t { MODE_LOCK, MODE_NORMAL, MODE_CONFIG };
ControlMode mode = MODE_LOCK;
float pitch = 0, roll = 0, pitchOffset = 0, rollOffset = 0;
float pitchRaw = 0, rollRaw = 0;
float pitchHigh = 20, rollLow = 10, rollMid = 20, rollHigh = 30;
uint8_t pwmMin = 70, pwmMid = 130, pwmMax = 255;
int8_t velocity = 0, rotation = 0;
uint32_t lastImuRead = 0;

// ---------------- Botão ----------------
bool previousButton = HIGH;
uint32_t pressedAt = 0, lastClickAt = 0;
bool holdActionDone = false, rebindHoldDone = false;
uint8_t clickCount = 0;

void setLed(uint8_t r, uint8_t g, uint8_t b) {
  // LED RGB de ânodo comum.
  uint8_t limitedR = (uint16_t)r * LED_MAX_BRIGHTNESS / 255;
  uint8_t limitedG = (uint16_t)g * LED_MAX_BRIGHTNESS / 255;
  uint8_t limitedB = (uint16_t)b * LED_MAX_BRIGHTNESS / 255;
  analogWrite(LED_R, 255 - limitedR); analogWrite(LED_G, 255 - limitedG); analogWrite(LED_B, 255 - limitedB);
}
void ledOff() { setLed(0, 0, 0); }
void beep(uint8_t count) {
  for (uint8_t i = 0; i < count; i++) {
    digitalWrite(BUZZER, HIGH); delay(35); digitalWrite(BUZZER, LOW); delay(35);
  }
}
void updateLed() {
  if (mode == MODE_CONFIG) { setLed(0, 150, 150); return; }
  if (mode == MODE_LOCK) { setLed(bleConnected ? 255 : 180, 0, 0); return; }
  if (bleConnected) { setLed(0, 255, 0); return; }
  uint8_t v = (millis() / 8) % 255;
  setLed(0, 0, v < 128 ? v * 2 : (255 - v) * 2);
}

void writeReg(uint8_t reg, uint8_t value) {
  Wire.beginTransmission(MPU_ADDR); Wire.write(reg); Wire.write(value); Wire.endTransmission();
}
uint8_t readReg(uint8_t reg) {
  Wire.beginTransmission(MPU_ADDR); Wire.write(reg); Wire.endTransmission(false);
  Wire.requestFrom(MPU_ADDR, (uint8_t)1); return Wire.available() ? Wire.read() : 0;
}
void readMpu() {
  Wire.beginTransmission(MPU_ADDR); Wire.write(ACCEL_XOUT_H); Wire.endTransmission(false);
  if (Wire.requestFrom(MPU_ADDR, (uint8_t)14) != 14) return;
  int16_t ax = (Wire.read() << 8) | Wire.read();
  int16_t ay = (Wire.read() << 8) | Wire.read();
  int16_t az = (Wire.read() << 8) | Wire.read();
  Wire.read(); Wire.read(); Wire.read(); Wire.read(); Wire.read(); Wire.read(); Wire.read(); Wire.read();
  float fax = ax, fay = ay, faz = az;
  // A IMU está montada com os eixos lógicos trocados na estrutura:
  // o eixo calculado originalmente como roll deve controlar pitch,
  // e o eixo calculado originalmente como pitch deve controlar roll.
  float physicalPitch = atan2(fay, sqrt(fax * fax + faz * faz)) * 180.0f / PI;
  float physicalRoll = atan2(fax, sqrt(fay * fay + faz * faz)) * 180.0f / PI;
  // Mantém a orientação física já ajustada: physicalRoll -> pitch e
  // physicalPitch -> roll. Os valores raw permitem zerar sem acumular offset.
  pitchRaw = INVERT_PITCH ? -physicalRoll : physicalRoll;
  rollRaw = INVERT_ROLL ? physicalPitch : -physicalPitch;
  pitch = pitchRaw - pitchOffset;
  roll = rollRaw - rollOffset;
}
void calibrateAngles() {
  float pitchSum = 0, rollSum = 0;
  for (uint8_t sample = 0; sample < 20; sample++) {
    readMpu();
    pitchSum += pitchRaw;
    rollSum += rollRaw;
    delay(5);
  }
  // Zerar significa capturar a posição atual, não somar a posição atual
  // ao offset anterior. A soma fazia a calibração degradar a cada clique.
  pitchOffset = pitchSum / 20.0f;
  rollOffset = rollSum / 20.0f;
  pitch = 0;
  roll = 0;
  prefs.begin("angles", false); prefs.putFloat("pitchOff", pitchOffset); prefs.putFloat("rollOff", rollOffset); prefs.end();
  Serial.printf("[CAL] pitchOffset=%.2f rollOffset=%.2f\n", pitchOffset, rollOffset); beep(1);
}

void loadSettings() {
  prefs.begin("angles", true);
  pitchHigh = prefs.getFloat("pitchHigh", 20); rollLow = prefs.getFloat("rollLow", 10);
  rollMid = prefs.getFloat("rollMid", 20); rollHigh = prefs.getFloat("rollHigh", 30);
  pitchOffset = prefs.getFloat("pitchOff", 0); rollOffset = prefs.getFloat("rollOff", 0); prefs.end();
  prefs.begin("pwm", true); pwmMin = prefs.getUChar("min", 70); pwmMid = prefs.getUChar("mid", 130); pwmMax = prefs.getUChar("max", 255); prefs.end();
}
void saveAngles() {
  prefs.begin("angles", false); prefs.putFloat("pitchHigh", pitchHigh); prefs.putFloat("rollLow", rollLow); prefs.putFloat("rollMid", rollMid); prefs.putFloat("rollHigh", rollHigh); prefs.end();
}
void savePwm() {
  prefs.begin("pwm", false); prefs.putUChar("min", pwmMin); prefs.putUChar("mid", pwmMid); prefs.putUChar("max", pwmMax); prefs.end();
}

uint8_t crc8(const String &payload) { uint16_t sum = 0; for (size_t i = 0; i < payload.length(); i++) sum += (uint8_t)payload[i]; return (uint8_t)sum; }
String makeFrame(const String &payload) {
  char crc[3]; snprintf(crc, sizeof(crc), "%02X", crc8(payload)); return "@" + payload + "*" + crc + ";";
}
void sendBle(const String &payload) {
  if (!bleConnected || dataChar == nullptr) return;
  String out = USE_V3_FRAMES ? makeFrame(payload) : payload;
  dataChar->writeValue((uint8_t *)out.c_str(), out.length(), true);
}

void sendMotionStop() {
  velocity = 0;
  rotation = 0;
  sequenceNo++;
  // O frame de movimento zerado elimina qualquer comando R/L persistente
  // no receptor; STOP é mantido como compatibilidade com o firmware antigo.
  sendBle("D,V=0,R=0,S=" + String(sequenceNo));
  sendBle("STOP");
}

void stopConfigBle();

void sendConfigReply(const String &text) {
  if (configChar == nullptr) return;
  configChar->setValue(text.c_str());
  configChar->notify();
}

void processConfigCommand(String line) {
  line.trim(); line.toUpperCase();
  if (line == "STATUS") {
    sendConfigReply("STATUS,MODE=CONFIG,BLE=" + String(bleConnected ? 1 : 0));
  } else if (line == "CAL") {
    calibrateAngles(); sendConfigReply("OK,CAL");
  } else if (line == "ANGLES?") {
    sendConfigReply("ANGLES=" + String(pitchHigh, 1) + "," + String(rollLow, 1) + "," + String(rollMid, 1) + "," + String(rollHigh, 1));
  } else if (line.startsWith("ANGLES=")) {
    float a, b, c, d;
    if (sscanf(line.c_str() + 7, "%f,%f,%f,%f", &a, &b, &c, &d) == 4 && a > 0 && b > 0 && b <= c && c <= d && d <= 90) {
      pitchHigh = a; rollLow = b; rollMid = c; rollHigh = d; saveAngles(); sendConfigReply("OK,ANGLES");
    } else sendConfigReply("ERR,ANGLES");
  } else if (line == "PWM?") {
    sendConfigReply("PWM=" + String(pwmMin) + "," + String(pwmMid) + "," + String(pwmMax));
  } else if (line.startsWith("PWM=")) {
    int a, b, c;
    if (sscanf(line.c_str() + 4, "%d,%d,%d", &a, &b, &c) == 3 && a >= 0 && a <= b && b <= c && c <= 255) {
      pwmMin = a; pwmMid = b; pwmMax = c; savePwm(); sendConfigReply("OK,PWM");
    } else sendConfigReply("ERR,PWM");
  } else if (line == "EXIT") {
    sendConfigReply("OK,EXIT"); stopConfigBle(); mode = MODE_LOCK;
  } else sendConfigReply("ERR,COMMAND");
}

class ConfigCallbacks : public BLECharacteristicCallbacks {
  void onWrite(BLECharacteristic *characteristic) override {
    String command = characteristic->getValue().c_str();
    if (mode == MODE_CONFIG) processConfigCommand(command);
  }
};

void stopConfigBle() {
  if (!configBleActive) return;
  BLEDevice::getAdvertising()->stop();
  configBleActive = false;
  Serial.println("[CFG] BLE de configuração encerrado");
}

void startConfigBle() {
  if (configBleActive) return;
  if (configServer == nullptr) configServer = BLEDevice::createServer();
  BLEService *service = configServer->createService(CONFIG_SERVICE_UUID);
  configChar = service->createCharacteristic(CONFIG_CHAR_UUID, BLECharacteristic::PROPERTY_READ | BLECharacteristic::PROPERTY_WRITE | BLECharacteristic::PROPERTY_NOTIFY);
  configChar->addDescriptor(new BLE2902());
  configChar->setCallbacks(new ConfigCallbacks());
  configChar->setValue("READY");
  service->start();
  BLEAdvertising *advertising = BLEDevice::getAdvertising();
  advertising->addServiceUUID(CONFIG_SERVICE_UUID);
  advertising->setScanResponse(true);
  advertising->start();
  configBleActive = true;
  Serial.println("[CFG] BLE ativo: CONTROLE-CFG");
}

void toggleConfigMode() {
  if (mode == MODE_CONFIG) {
    sendMotionStop(); stopConfigBle(); mode = MODE_LOCK; beep(2);
    Serial.println("[CFG] saindo; controle permanece LOCK");
  } else {
    sendMotionStop(); mode = MODE_CONFIG; startConfigBle(); beep(1);
    Serial.println("[CFG] modo de configuração BLE");
  }
}

void calculateCommand() {
  bool front = digitalRead(BTN_FRONT) == LOW, back = digitalRead(BTN_BACK) == LOW;
  velocity = 0; rotation = 0;
  if (front != back && mode == MODE_NORMAL) {
    if (front) velocity = pitch > pitchHigh ? 1 : pitch < -pitchHigh ? 3 : 2;
    else velocity = pitch < -pitchHigh ? -1 : pitch > pitchHigh ? -3 : -2;
  }
  if (mode == MODE_NORMAL) {
    if (roll > rollHigh) rotation = 3; else if (roll > rollMid) rotation = 2; else if (roll > rollLow) rotation = 1;
    else if (roll < -rollHigh) rotation = -3; else if (roll < -rollMid) rotation = -2; else if (roll < -rollLow) rotation = -1;
  }
}
void sendCurrentCommand() {
  if (USE_V3_FRAMES) {
    sequenceNo++;
    sendBle("D,V=" + String(velocity) + ",R=" + String(rotation) + ",S=" + String(sequenceNo));
  } else {
    String v = velocity == 0 ? "V0" : velocity > 0 ? "VF" + String(velocity) : "VB" + String(-velocity);
    String r = rotation == 0 ? "0" : rotation > 0 ? "R" + String(rotation) : "L" + String(-rotation);
    sendBle(v + "," + r);
  }
}

class AdvertisedCallbacks : public BLEAdvertisedDeviceCallbacks {
  void onResult(BLEAdvertisedDevice device) override {
    if (!device.haveName()) return;
    String name = device.getName().c_str();
    if (!name.startsWith(TARGET_PREFIX)) return;
    BLEDevice::getScan()->stop();
    if (candidate) delete candidate;
    candidate = new BLEAdvertisedDevice(device);
    deviceName = name; connectRequested = true;
  }
};
class ClientCallbacks : public BLEClientCallbacks {
  void onConnect(BLEClient *) override { bleConnected = true; retryAt = 0; Serial.println("[BLE] conectado"); beep(2); }
  void onDisconnect(BLEClient *) override { bleConnected = false; dataChar = nullptr; Serial.println("[BLE] desconectado"); rescanRequested = true; }
};
void startScan() {
  BLEScan *scan = BLEDevice::getScan();
  if (!scanCallbackInstalled) { scan->setAdvertisedDeviceCallbacks(new AdvertisedCallbacks()); scan->setActiveScan(true); scan->setInterval(80); scan->setWindow(50); scanCallbackInstalled = true; }
  Serial.println("[BLE] procurando CARRINHO..."); scan->start(4, false);
}
void clearBind() {
  prefs.begin("ble", false); prefs.remove("mac"); prefs.end(); boundMac = "";
}
void saveBind(const String &mac) { prefs.begin("ble", false); prefs.putString("mac", mac); prefs.end(); boundMac = mac; }
void disconnectBle() { if (client && client->isConnected()) client->disconnect(); bleConnected = false; dataChar = nullptr; }
void rebind() {
  sendMotionStop(); stopConfigBle(); disconnectBle(); clearBind(); mode = MODE_LOCK; velocity = rotation = 0; connectRequested = false; rescanRequested = true; retryAt = millis() + 300; beep(3); Serial.println("[BIND] vínculo apagado; novo scan será iniciado");
}
void loadBind() { prefs.begin("ble", true); boundMac = prefs.getString("mac", ""); prefs.end(); }

bool connectTarget() {
  if (!client) { client = BLEDevice::createClient(); client->setClientCallbacks(new ClientCallbacks()); }
  bool ok = false;
  if (candidate) ok = client->connect(candidate);
  else if (boundMac.length()) ok = client->connect(BLEAddress(boundMac.c_str()));
  if (!ok) { Serial.println("[BLE] conexão falhou"); return false; }
  BLERemoteService *service = client->getService(SERVICE_UUID);
  if (!service) { client->disconnect(); return false; }
  dataChar = service->getCharacteristic(DATA_UUID);
  if (!dataChar || !dataChar->canWrite()) { client->disconnect(); dataChar = nullptr; return false; }
  if (!boundMac.length() && candidate) saveBind(candidate->getAddress().toString().c_str());
  if (dataChar->canNotify()) dataChar->registerForNotify([](BLERemoteCharacteristic *, uint8_t *data, size_t len, bool) { Serial.printf("[RX] %.*s\n", (int)len, data); });
  sendBle("STOP"); return true;
}

void toggleLock() {
  if (mode == MODE_CONFIG) return;
  mode = mode == MODE_LOCK ? MODE_NORMAL : MODE_LOCK;
  if (mode == MODE_LOCK) sendMotionStop(); else { velocity = 0; rotation = 0; }
  Serial.println(mode == MODE_LOCK ? "[MODE] LOCK" : "[MODE] NORMAL"); beep(mode == MODE_LOCK ? 2 : 1);
}
void handleLockButton() {
  bool current = digitalRead(BTN_LOCK); uint32_t now = millis();
  if (previousButton == HIGH && current == LOW) { pressedAt = now; holdActionDone = false; rebindHoldDone = false; }
  if (current == LOW && !holdActionDone && now - pressedAt >= 5000) { holdActionDone = true; toggleConfigMode(); }
  if (current == LOW && !rebindHoldDone && now - pressedAt >= 10000) { rebindHoldDone = true; rebind(); }
  if (previousButton == LOW && current == HIGH && !holdActionDone) {
    if (now - lastClickAt < 450) { clickCount = 0; toggleLock(); }
    else { clickCount = 1; lastClickAt = now; }
  }
  if (clickCount == 1 && now - lastClickAt > 450) { clickCount = 0; if (mode != MODE_CONFIG) calibrateAngles(); }
  previousButton = current;
}

void printHelp() {
  Serial.println("HELP STATUS LOCK UNLOCK CAL REBIND ANGLES? ANGLES=a,b,c,d PWM? PWM=min,mid,max");
}
void processSerial(String line) {
  line.trim(); line.toUpperCase();
  if (line == "HELP") printHelp(); else if (line == "STATUS") Serial.printf("mode=%s ble=%d name=%s mac=%s pitch=%.1f roll=%.1f rawPitch=%.1f rawRoll=%.1f\n", mode == MODE_CONFIG ? "CONFIG" : mode == MODE_LOCK ? "LOCK" : "NORMAL", bleConnected, deviceName.c_str(), boundMac.c_str(), pitch, roll, pitchRaw, rollRaw);
  else if (line == "LOCK") { mode = MODE_LOCK; sendMotionStop(); }
  else if (line == "UNLOCK") { mode = MODE_NORMAL; velocity = 0; rotation = 0; sendMotionStop(); }
  else if (line == "CAL") calibrateAngles();
  else if (line == "REBIND") rebind();
  else if (line == "ANGLES?") Serial.printf("ANGLES=%.1f,%.1f,%.1f,%.1f\n", pitchHigh, rollLow, rollMid, rollHigh);
  else if (line.startsWith("ANGLES=")) { sscanf(line.c_str() + 7, "%f,%f,%f,%f", &pitchHigh, &rollLow, &rollMid, &rollHigh); saveAngles(); }
  else if (line == "PWM?") Serial.printf("PWM=%u,%u,%u\n", pwmMin, pwmMid, pwmMax);
  else if (line.startsWith("PWM=")) { int a,b,c; if (sscanf(line.c_str()+4, "%d,%d,%d", &a,&b,&c)==3 && a>=0 && a<=b && b<=c && c<=255) { pwmMin=a; pwmMid=b; pwmMax=c; savePwm(); sendBle("C,UNLOCK"); delay(100); sendBle("C,PROFILE," + String(pwmMin) + "," + String(pwmMid) + "," + String(pwmMax)); } }
  else if (line.length()) Serial.println("[CMD] desconhecido; use HELP");
}

void setup() {
  Serial.begin(115200); pinMode(BTN_FRONT, INPUT_PULLUP); pinMode(BTN_BACK, INPUT_PULLUP); pinMode(BTN_LOCK, INPUT_PULLUP); pinMode(BUZZER, OUTPUT);
  pinMode(LED_R, OUTPUT); pinMode(LED_G, OUTPUT); pinMode(LED_B, OUTPUT); ledOff();
  Wire.begin(SDA_PIN, SCL_PIN); writeReg(PWR_MGMT_1, 0); writeReg(ACCEL_CONFIG, 0x10); loadSettings(); loadBind();
  uint8_t id = readReg(WHO_AM_I); Serial.printf("[BOOT] MPU WHO_AM_I=0x%02X\n", id); printHelp();
  mode = MODE_LOCK; BLEDevice::init("ESP32_Remote_V3");
  if (boundMac.length()) connectRequested = true; else rescanRequested = true;
}
void loop() {
  uint32_t now = millis();
  if (Serial.available()) processSerial(Serial.readStringUntil('\n'));
  handleLockButton();
  if (now - lastImuRead >= 20) { lastImuRead = now; readMpu(); calculateCommand(); }
  if (connectRequested && !bleConnected) { connectRequested = false; if (!connectTarget()) { rescanRequested = true; } }
  if (rescanRequested && !bleConnected && (int32_t)(now - retryAt) >= 0) { rescanRequested = false; retryAt = now + BLE_RETRY_MS; startScan(); }
  if (bleConnected && now - lastHeartbeat >= HEARTBEAT_MS) { lastHeartbeat = now; if (mode == MODE_NORMAL) sendCurrentCommand(); else sendMotionStop(); }
  updateLed();
}

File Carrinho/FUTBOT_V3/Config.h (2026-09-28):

#pragma once

#include <Arduino.h>

// ============================================================
// CONFIGURAÇÃO PRINCIPAL DO ROBÔ
// Edite principalmente LED_ACTIVE_HIGH ao trocar de carrinho.
// true  = LED com catodo comum: HIGH acende
// false = LED com anodo comum: LOW acende
// ============================================================
const bool LED_ACTIVE_HIGH = false;
const uint8_t BLE_CONNECTED_LEVEL = HIGH;

// Motores: Arduino Nano + TB6612FNG
const uint8_t MOTOR_LEFT_IN1 = A3;
const uint8_t MOTOR_LEFT_IN2 = A4;
const uint8_t MOTOR_LEFT_PWM = 3;
const uint8_t MOTOR_RIGHT_IN1 = A1;
const uint8_t MOTOR_RIGHT_IN2 = A2;
const uint8_t MOTOR_RIGHT_PWM = 5;

// HM-10
const uint8_t BLE_STATE_PIN = 7;
const uint32_t BLE_BAUD = 38400;

// LEDs do carrinho
const uint8_t LED_GREEN_1 = 6;
const uint8_t LED_GREEN_2 = 9;
const uint8_t LED_GREEN_3 = 10;
const uint8_t LED_RED = 4;
const uint8_t LED_BLUE = 2;

// Ajustes de comportamento
const uint32_t MOTOR_FAILSAFE_MS = 300;
const uint32_t CONFIG_UNLOCK_MS = 5000;
const uint8_t DEFAULT_PWM_MIN = 45;
const uint8_t DEFAULT_PWM_MED = 85;
const uint8_t DEFAULT_PWM_MAX = 135;

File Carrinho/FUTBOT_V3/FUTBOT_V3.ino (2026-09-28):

/*
  RoverLab - firmware V3
  Arduino Nano + TB6612FNG + HM-10

  Protocolo V3 ASCII enquadrado:
    @D,V=2,R=0,S=1*CRC;
    @C,UNLOCK*CRC;
    @C,PROFILE,35,80,135*CRC;
    @C,GET*CRC;
    @STOP*CRC;

  CRC8 e soma modulo 256 dos bytes do payload, sem '@', '*' ou ';'.
  O CRC e transmitido em dois digitos hexadecimais.

  Compatibilidade opcional com o protocolo antigo:
    VF2,R1 / VB1,L2 / V0,0
  Ative LEGACY_COMPAT somente durante a migracao.

  Pinagem:
    Motor esquerdo: AIN1=A3, AIN2=A4, PWMA=D3
    Motor direito:  BIN1=A1, BIN2=A2, PWMB=D5
    BLE STATE: D7
    HM-10: Serial D0/D1, 38400 baud
*/

#include <Arduino.h>
#include <EEPROM.h>
#include <stdio.h>
#include <string.h>
#include "Config.h"
#include "Leds.h"

const uint8_t AIN1 = MOTOR_LEFT_IN1, AIN2 = MOTOR_LEFT_IN2, PWMA = MOTOR_LEFT_PWM;
const uint8_t BIN1 = MOTOR_RIGHT_IN1, BIN2 = MOTOR_RIGHT_IN2, PWMB = MOTOR_RIGHT_PWM;
const uint8_t BLE_STATE = BLE_STATE_PIN;

const bool LEGACY_COMPAT = true;
const uint32_t FAILSAFE_MS = MOTOR_FAILSAFE_MS;
const uint32_t UNLOCK_MS = CONFIG_UNLOCK_MS;
const uint8_t FRAME_MAX = 180;
const uint8_t PWM_DEFAULT[4] = {0, DEFAULT_PWM_MIN, DEFAULT_PWM_MED, DEFAULT_PWM_MAX};

// Programa: cada instrução ocupa 3 bytes: opcode, parâmetro e duração em 100 ms.
// Os slots ficam depois dos slots do perfil no EEPROM de 1 KB do Nano.
const uint8_t PROGRAM_MAGIC = 0xB6;
const uint8_t PROGRAM_VERSION = 1;
const uint16_t PROGRAM_SLOT_A = 32;
const uint16_t PROGRAM_SLOT_B = 256;
const uint16_t PROGRAM_HEADER_SIZE = 10;
const uint16_t MAX_PROGRAM_BYTES = 160;
const uint8_t OP_FORWARD = 0x01;
const uint8_t OP_BACKWARD = 0x02;
const uint8_t OP_LEFT = 0x03;
const uint8_t OP_RIGHT = 0x04;
const uint8_t OP_STOP = 0x05;
const uint8_t OP_WAIT = 0x06;
const uint8_t OP_END = 0xFF;

// Dois slots permitem recuperar o perfil anterior se faltar energia durante a escrita.
const uint8_t PROFILE_MAGIC = 0xA7;
const uint16_t SLOT_A = 0;
const uint16_t SLOT_B = 16;
struct ProfileRecord {
  uint8_t magic;
  uint8_t version;
  uint8_t sequence;
  uint8_t minPwm;
  uint8_t medPwm;
  uint8_t maxPwm;
  uint8_t crc;
};

uint8_t pwmLevel[4] = {0, DEFAULT_PWM_MIN, DEFAULT_PWM_MED, DEFAULT_PWM_MAX};
uint8_t currentLevel = 3;
uint8_t activeSequence = 0;
uint16_t activeSlot = SLOT_A;
uint32_t lastValidCommand = 0;
uint32_t unlockUntil = 0;

uint8_t uploadBuffer[MAX_PROGRAM_BYTES];
uint16_t uploadLength = 0;
uint16_t uploadExpectedLength = 0;
uint16_t uploadExpectedCrc = 0;
bool uploadOpen = false;
uint16_t activeProgramLength = 0;
uint16_t activeProgramCrc = 0;
uint8_t activeProgramSequence = 0;
uint16_t activeProgramSlot = PROGRAM_SLOT_A;
bool programRunning = false;
uint16_t programPc = 0;
uint32_t programStepUntil = 0;

char frame[FRAME_MAX + 1];
uint8_t frameLength = 0;
bool inFrame = false;

void reply(const char *payload);
void stopMotors();
void applyDrive(int8_t velocity, int8_t rotation);

uint8_t crc8(const char *text) {
  uint16_t sum = 0;
  while (*text) sum += (uint8_t)*text++;
  return (uint8_t)(sum & 0xFF);
}

uint16_t crc16(const uint8_t *data, uint16_t length) {
  uint16_t crc = 0xFFFF;
  while (length--) {
    crc ^= (uint16_t)*data++ << 8;
    for (uint8_t bit = 0; bit < 8; bit++) crc = (crc & 0x8000) ? (crc << 1) ^ 0x1021 : crc << 1;
  }
  return crc;
}

uint16_t programHeaderCrc(uint16_t length, uint16_t programCrc, uint8_t sequence) {
  uint8_t header[5] = {PROGRAM_MAGIC, PROGRAM_VERSION, sequence, (uint8_t)(length >> 8), (uint8_t)length};
  header[3] = (uint8_t)(length >> 8);
  header[4] = (uint8_t)length;
  uint16_t crc = crc16(header, sizeof(header));
  uint8_t crcBytes[2] = {(uint8_t)(programCrc >> 8), (uint8_t)programCrc};
  return crc16(crcBytes, 2) ^ crc;
}

bool validProgramHeader(uint16_t slot, uint16_t *length, uint16_t *programCrc, uint8_t *sequence) {
  uint8_t magic = EEPROM.read(slot);
  uint8_t version = EEPROM.read(slot + 1);
  if (magic != PROGRAM_MAGIC || version != PROGRAM_VERSION) return false;
  *sequence = EEPROM.read(slot + 2);
  *length = ((uint16_t)EEPROM.read(slot + 3) << 8) | EEPROM.read(slot + 4);
  *programCrc = ((uint16_t)EEPROM.read(slot + 5) << 8) | EEPROM.read(slot + 6);
  uint16_t storedHeaderCrc = ((uint16_t)EEPROM.read(slot + 7) << 8) | EEPROM.read(slot + 8);
  if (*length == 0 || *length > MAX_PROGRAM_BYTES) return false;
  uint8_t data[MAX_PROGRAM_BYTES];
  for (uint16_t i = 0; i < *length; i++) data[i] = EEPROM.read(slot + PROGRAM_HEADER_SIZE + i);
  return crc16(data, *length) == *programCrc && programHeaderCrc(*length, *programCrc, *sequence) == storedHeaderCrc;
}

bool newerSequence(uint8_t candidate, uint8_t current) {
  return (uint8_t)(candidate - current) < 128 && candidate != current;
}

void loadProgram() {
  uint16_t lengthA = 0, lengthB = 0, crcA = 0, crcB = 0;
  uint8_t sequenceA = 0, sequenceB = 0;
  bool validA = validProgramHeader(PROGRAM_SLOT_A, &lengthA, &crcA, &sequenceA);
  bool validB = validProgramHeader(PROGRAM_SLOT_B, &lengthB, &crcB, &sequenceB);
  if (!validA && !validB) { activeProgramLength = 0; return; }
  bool chooseB = validB && (!validA || newerSequence(sequenceB, sequenceA));
  activeProgramSlot = chooseB ? PROGRAM_SLOT_B : PROGRAM_SLOT_A;
  activeProgramLength = chooseB ? lengthB : lengthA;
  activeProgramCrc = chooseB ? crcB : crcA;
  activeProgramSequence = chooseB ? sequenceB : sequenceA;
}

void writeProgramSlot(uint16_t slot, const uint8_t *data, uint16_t length, uint16_t programCrc, uint8_t sequence) {
  // Dados são escritos antes do cabeçalho. O magic só é marcado por último.
  EEPROM.update(slot, 0);
  for (uint16_t i = 0; i < length; i++) EEPROM.update(slot + PROGRAM_HEADER_SIZE + i, data[i]);
  EEPROM.update(slot + 1, PROGRAM_VERSION);
  EEPROM.update(slot + 2, sequence);
  EEPROM.update(slot + 3, length >> 8);
  EEPROM.update(slot + 4, length & 0xFF);
  EEPROM.update(slot + 5, programCrc >> 8);
  EEPROM.update(slot + 6, programCrc & 0xFF);
  uint16_t headerCrc = programHeaderCrc(length, programCrc, sequence);
  EEPROM.update(slot + 7, headerCrc >> 8);
  EEPROM.update(slot + 8, headerCrc & 0xFF);
  EEPROM.update(slot + 9, OP_END);
  EEPROM.update(slot, PROGRAM_MAGIC);
}

bool validProgramInstruction(uint16_t pc) {
  if (pc + 2 >= uploadLength) return false;
  uint8_t opcode = uploadBuffer[pc];
  uint8_t level = uploadBuffer[pc + 1];
  if (opcode < OP_FORWARD || opcode > OP_WAIT) return opcode == OP_END;
  if (opcode == OP_STOP) return level == 0;
  return opcode == OP_WAIT ? level == 0 : level >= 1 && level <= 3;
}

void stopProgram() {
  programRunning = false;
  stopMotors();
}

void startProgram() {
  if (!activeProgramLength) { reply("ERR,NO_PROGRAM"); return; }
  programRunning = true;
  programPc = 0;
  programStepUntil = millis();
  reply("OK,P,START");
}
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

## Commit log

2026-08-23 Adicionando pastas do projeto
    [Botão_externo.stl, Botão_interno.stl, CASE_EXT.stl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]
2026-09-28 Atualizado o firmware de controle do carrinho
